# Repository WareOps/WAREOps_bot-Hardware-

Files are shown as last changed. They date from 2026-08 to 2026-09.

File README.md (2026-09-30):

# Warehouse Bot & Active Vision System (ROS2 Humble)

An end-to-end Autonomous Mobile Robot (AMR) system for warehouse navigation, mapping, and active vision rack inventory scanning developed using **ROS2 Humble**.

---

##  Video Demonstrations & Project Demos



*  **[Watch Complete Project Demonstration Playlist on YouTube](https://youtube.com/playlist?list=PLdkPHi9wHG-M&si=vZzbjLmxS52RyPB2)** — Includes full autonomous navigation tours, SLAM mapping, active vision pan-tilt QR scanning, and hardware testing demonstrations.

---

##  System Architecture & Package Deployment Split

The repository is structured for a multi-device deployment between the **onboard Raspberry Pi 4** (robot hardware control & navigation) and the **Local Computer** (operator station, active vision processing, teleoperation, and visualization).

```text
               +---------------------------------------------------+
               |             Wi-Fi / Network Subnet                |
               +-------------------------+-------------------------+
                                         |
            +----------------------------+----------------------------+
            |                                                         |
            v                                                         v
+-----------------------+                                 +-----------------------+
|   RASPBERRY PI 4    |                                 |   LOCAL COMPUTER    |
| (Robot Controller)    |                                 | (Operator Station)    |
+-----------------------+                                 +-----------------------+
| • pi_bot              |                                 | • active_vision_scanner|
| • serial              |                                 | • joy_teleop          |
| • diffdrive_arduino   |                                 | • rviz                |
+-----------+-----------+                                 | • Motors              |
            |                                             +-----------------------+
            v                                                         |
+-----------------------+                                             |
|  Hardware           |                                             v
| • Arduino Nano        |<============================================+
| • RPLidar A1M8        |   (ESP32-CAM MJPEG Stream & WiFi Servo HTTP)
| • Motor Drivers       |
+-----------------------+
```

---

##  Package Distribution Guide

###  Packages to clone on **Raspberry Pi** (Robot Hardware & Navigation)

| Package | Description |
|---|---|
| **`pi_bot`** | Core robot ROS2 bringup, URDF/Xacro models, RPLidar launch, SLAM Toolbox configurations, and Navigation2 launch stack. |
| **`serial`** | C++ serial library required by `diffdrive_arduino` to communicate over USB with the Arduino motor controller. |
| **`diffdrive_arduino`** | `ros2_control` hardware interface C++ plugin interfacing with Arduino Nano for differential drive wheel odometry and motor commands. |

###  Packages to clone on **Local Computer** (Workstation & Vision Processing)

| Package | Description |
|---|---|
| **`active_vision_scanner`** | Python ROS2 node for OpenCV active rack alignment, pan-tilt servo tracking, QR code scanner, database lookup (`warehouse_database.xlsx`), and CSV inventory logging. |
| **`joy_teleop`** | ROS2 node mapping USB joystick / gamepad input to `/cmd_vel` velocity commands for manual robot control. |
| **`rviz`** | Pre-configured RViz2 display profiles (`rviz_config.rviz`, `rviz_config_nav2.rviz`) for live map, costmap, TF, and LiDAR visualization. |
| **`Motors`** | Arduino Nano firmware (`ROSArduinoBridge`) sketch and driver headers for motor control, PID tuning, and encoder processing. |

---

##  Quick Start Guide

### 1. Prerequisites & Dependencies

Both machines must run **Ubuntu 22.04 LTS** with **ROS2 Humble** installed.

On **Raspberry Pi**:
```bash
sudo apt update
sudo apt install -y \
  ros-humble-ros2-control \
  ros-humble-ros2-controllers \
  ros-humble-slam-toolbox \
  ros-humble-navigation2 \
  ros-humble-nav2-bringup \
  ros-humble-rplidar-ros
```

On **Local Computer**:
```bash
sudo apt update
sudo apt install -y \
  ros-humble-rviz2 \
  ros-humble-joy \
  python3-opencv \
  python3-pandas \
  python3-openpyxl
pip install pyzbar "numpy<2"
```

---

### 2. Setting Up on Raspberry Pi

1. Create a ROS2 workspace and clone the Pi packages:
   ```bash
   mkdir -p ~/ros2_ws/src
   cd ~/ros2_ws/src
   # Copy or git clone pi_bot, serial, diffdrive_arduino into src/
   ```

2. Build and source:
   ```bash
   cd ~/ros2_ws
   colcon build --symlink-install
   source install/setup.bash
   ```

3. Export ROS Domain ID (must match Local PC):
   ```bash
   echo "export ROS_DOMAIN_ID=0" >> ~/.bashrc
   source ~/.bashrc
   ```

---

### 3. Setting Up on Local Computer

1. Create a ROS2 workspace and clone the Local PC packages:
   ```bash
   mkdir -p ~/ros2_ws/src
   cd ~/ros2_ws/src
   # Copy or git clone active_vision_scanner, joy_teleop, rviz, Motors into src/
   ```

2. Build and source:
   ```bash
   cd ~/ros2_ws
   colcon build --symlink-install
   source install/setup.bash
   ```

3. Export ROS Domain ID (must match Raspberry Pi):
   ```bash
   echo "export ROS_DOMAIN_ID=0" >> ~/.bashrc
   source ~/.bashrc
   ```

---

##  Running the System

### On Raspberry Pi (Robot Hardware Bringup):

```bash
# 1. Bring up robot state publisher and diffdrive hardware interface
ros2 launch pi_bot launch_robot.launch.py 

# 2. Launch SLAM Toolbox for mapping (or navigation for autonomous drive)
ros2 launch pi_bot slam_map.launch.py

# 3. Launch Nav2_bringup (navigation for autonomous drive with delayed initial pose setup)
ros2 launch pi_bot navigation.launch.py map:=/path/to/my_map.yaml

# 4. Optional: Run autonomous rack navigation script or full tour manager
python3 scripts/go_to_rack_r4_a3.py
python3 scripts/full_tour.py
```

### On Local Computer (Control & Inspection):

```bash
# 1. Run Joystick Teleop for manual navigation
ros2 launch joy_teleop teleop.launch.py

# 2. Launch RViz2 for visualization
rviz2 -d src/rviz/rviz_config_nav2.rviz

# 3. Launch Active Vision Scanner System
ros2 launch active_vision_scanner scanner_system.launch.py \
    esp32_ip:=192.168.43.XXX \
    esp32_cam_url:=http://192.168.43.YYY:81/stream
```

---

##  Repository Directory Tree

```text
src/
├── active_vision_scanner/  # [Local PC] ESP32 WiFi bridge & OpenCV QR scanner state machine
├── Chassis_step_file/      # 3D CAD step model file of the WareOps robot chassis
├── diffdrive_arduino/      # [Raspberry Pi] ros2_control C++ hardware interface plugin
├── Images/                 # High-resolution hardware and assembly gallery with README.md
├── joy_teleop/             # [Local PC] Joystick teleoperation node
├── Motors/                 # [Local PC] Arduino Nano motor firmware (ROSArduinoBridge)
├── pi_bot/                 # [Raspberry Pi] URDF, RPLidar driver, SLAM, & Nav2 launch configs
├── rviz/                   # [Local PC] RViz2 display configuration files
├── scripts/                # Autonomous navigation waypoint & full tour sequence scripts
│   ├── initialise.py       # Delayed initial pose setup script for Nav2
│   ├── full_tour.py        # Multi-rack automated inspection sequence manager
│   ├── go_to_rack_r3_b3.py # Waypoint navigation script for Rack R3_B3
│   ├── go_to_rack_r4_a2.py # Waypoint navigation script for Rack R4_A2
│   └── go_to_rack_r4_a3.py # Waypoint navigation script for Rack R4_A3
├── serial/                 # [Raspberry Pi] Serial communication C++ library
├── HARDWARE.md             # Complete hardware specification sheet
├── system_overview.md       # Detailed active vision system flow documentation
├── warehouse_database.xlsx # Master warehouse inventory Excel database
└── warehouse_database.ods  # Excel/ODS master inventory database file
```

---

##  Documentation Links
* [HARDWARE.md](HARDWARE.md): Detailed hardware connections, pinouts, and power distribution specs.
* [system_overview.md](system_overview.md): Complete breakdown of network architecture, ESP32 pan-tilt trajectory, and vision state machine flow.

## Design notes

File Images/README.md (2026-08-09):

# WareOps Bot - Hardware & Assembly Gallery

This directory contains high-resolution photographs detailing the physical hardware, internal electronics, sensor integration, wiring layout, and 3D-printing manufacturing process of the **WareOps Autonomous Warehouse Inspection Robot**.

---

## 🤖 System Overview & Feature Architecture

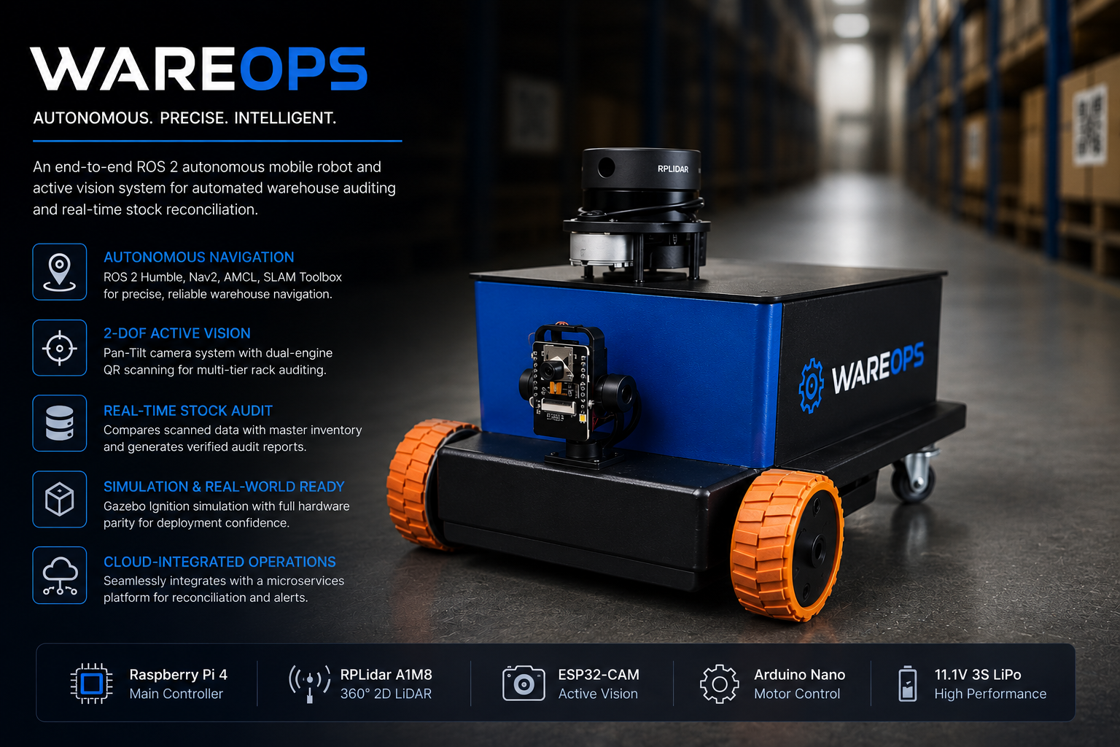
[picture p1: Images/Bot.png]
WareOps Bot System Overview

*WareOps Autonomous Mobile Robot hardware architecture, active vision pan-tilt system, sensor suite, and system capabilities overview.*

---

## 📸 Assembled Robot Views

### Robot Perspective Overview
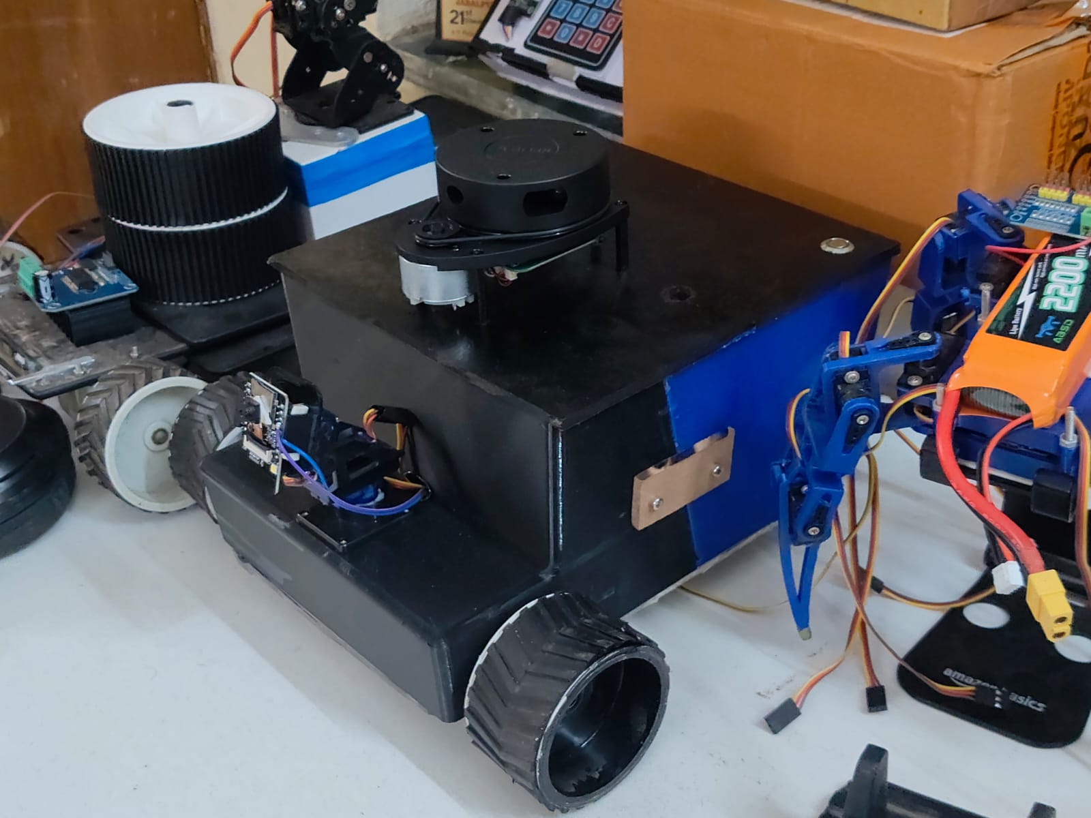
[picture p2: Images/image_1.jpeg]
WareOps Bot Side Perspective

*Side perspective view of the fully assembled robot showing the top-mounted RPLiDAR A1, front pan/tilt camera scanner, and differential drive wheels.*

### Front View & Sensor Alignment
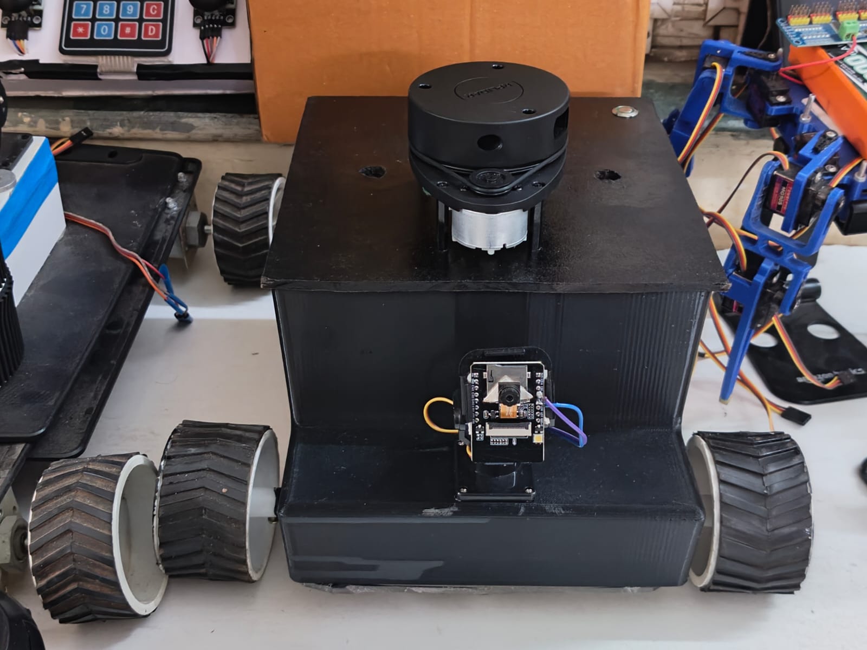
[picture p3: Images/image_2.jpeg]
WareOps Bot Front View

*Front view highlighting the active vision camera module mounted on a pan/tilt servo assembly and the top LiDAR.*

### Front-Isometric View
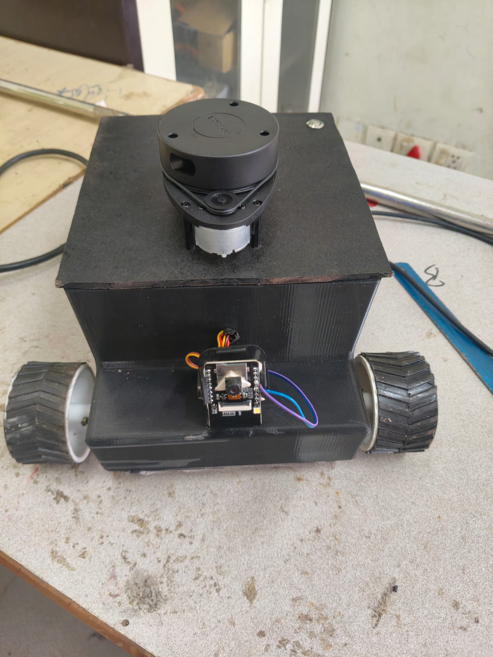
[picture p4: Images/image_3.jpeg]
WareOps Bot Isometric View

*Isometric view showing compact chassis design and wheel mounting.*

### Front Sensor Array
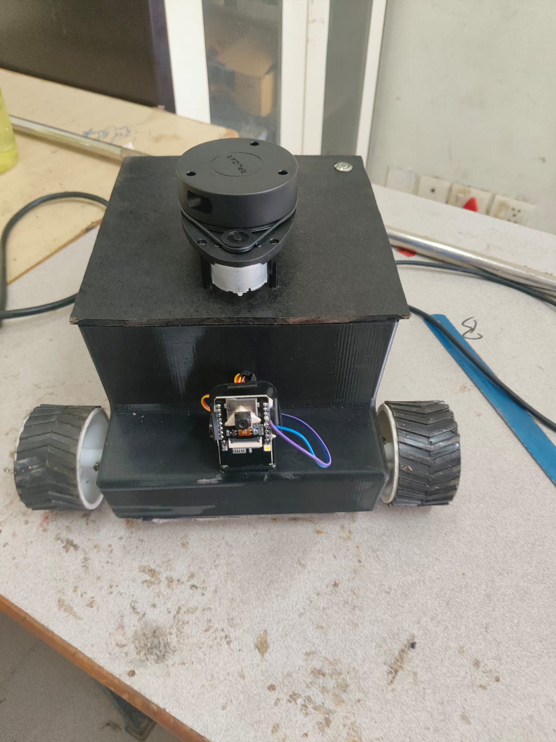
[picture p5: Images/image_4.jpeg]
WareOps Bot Sensor Array

*Close-up front view detailing sensor positioning for autonomous navigation and barcode/QR rack scanning.*

### Floor Navigation Testing
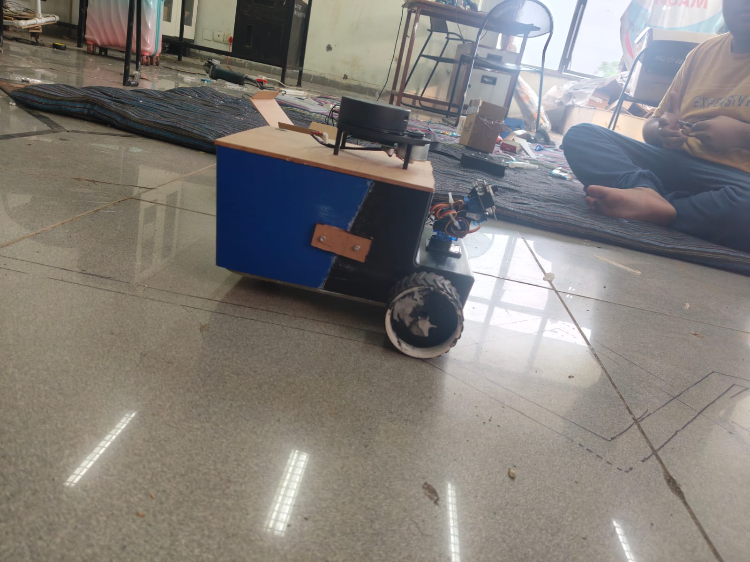
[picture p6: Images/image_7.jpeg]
WareOps Bot Floor Test

*Side profile of assembled robot undergoing mobility and ground-truth transform testing.*

### Navigation Test Grid
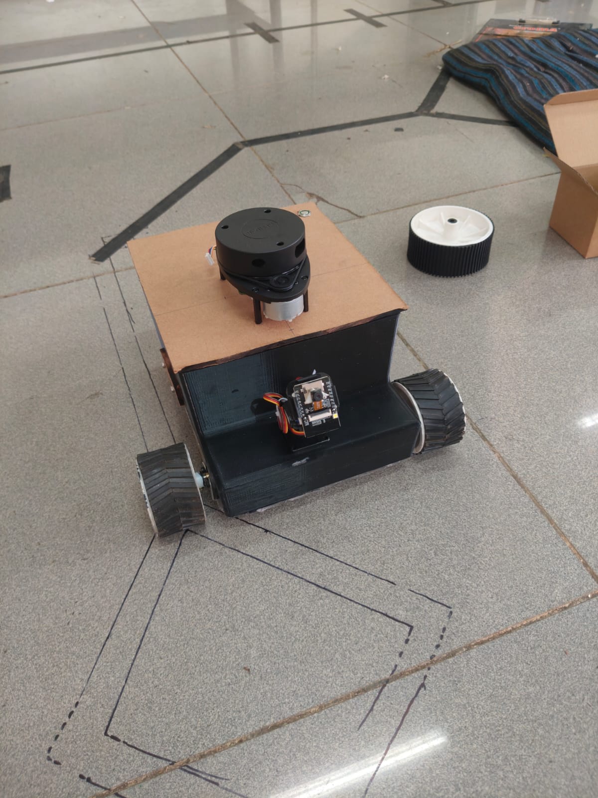
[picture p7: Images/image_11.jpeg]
WareOps Bot Navigation Grid

*Robot positioned on floor layout grid during AMCL localization calibration.*

---

## ⚡ Internal Electronics & Control Hardware

### Electronics Bay Overview
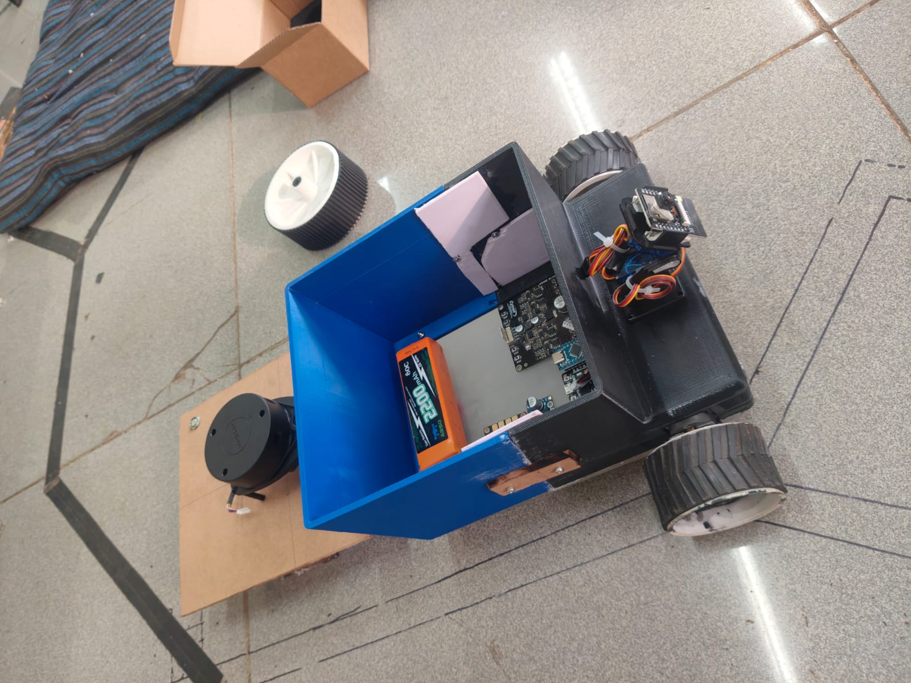
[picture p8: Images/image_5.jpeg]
Internal Electronics Layout

*Open chassis compartment displaying the LiPo battery placement, Cytron motor driver, and main controller board.*

### Control Board & Power Layout
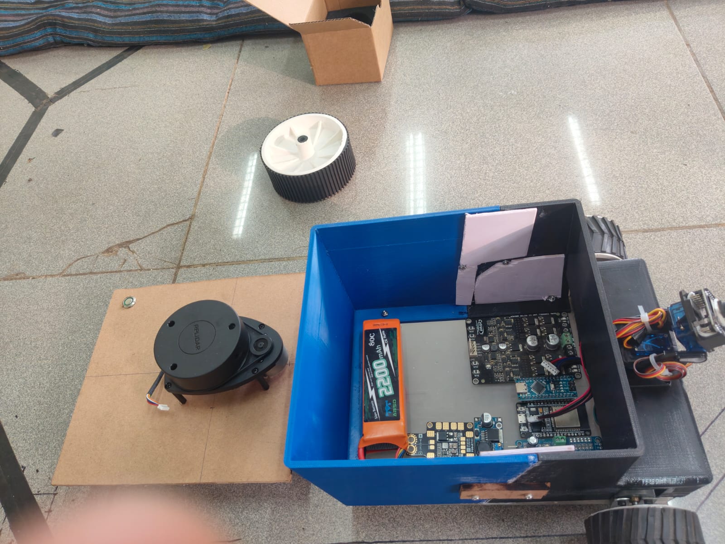
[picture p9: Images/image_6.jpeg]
Top Down Component View

*Top-down layout showing Cytron motor driver, microcontroller control board, DC-DC buck converters, and 2200mAh 3S LiPo battery.*

### Component Placement & Power Distribution
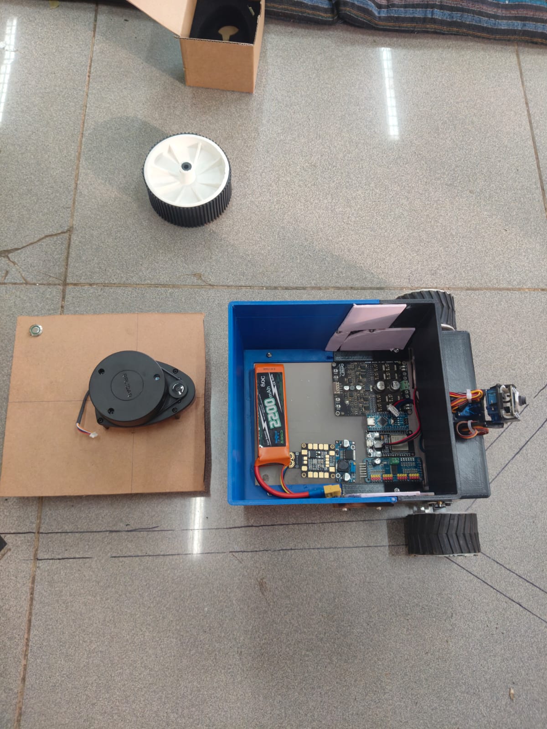
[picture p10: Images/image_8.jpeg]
Component Layout

*Overhead component mapping with top mounting plate detached.*

### High-Angle Hardware Layout
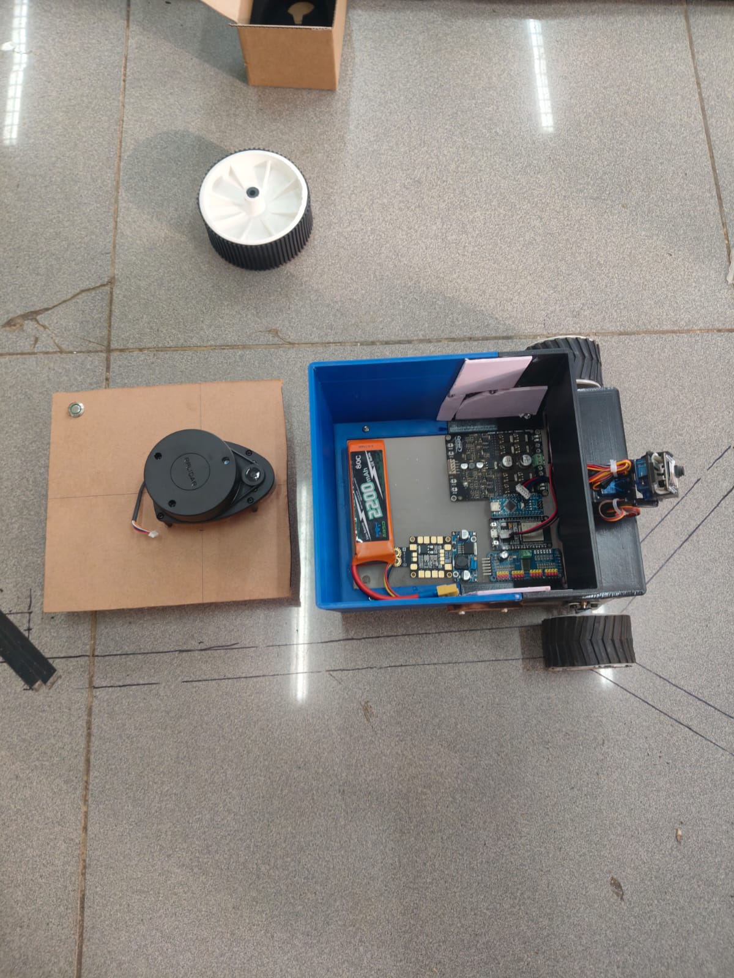
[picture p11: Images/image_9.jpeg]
High Angle Assembly Layout

*Component layout reference prior to top plate installation.*

### Electronics Board Close-Up
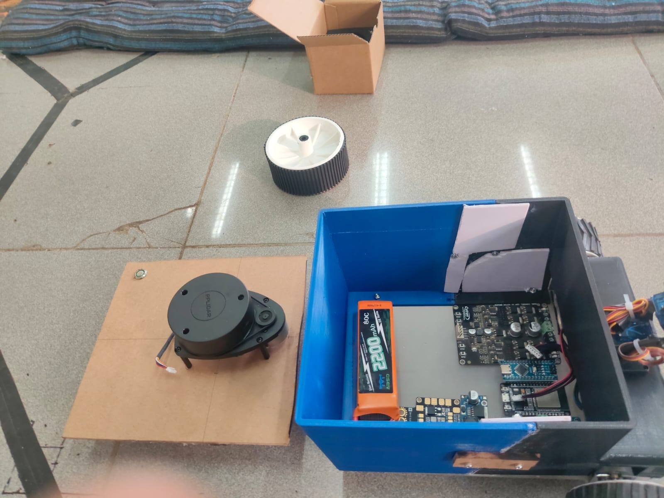
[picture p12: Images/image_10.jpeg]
Electronics Boards Close-Up

*Detailed close-up of motor drive electronics, power distribution circuitry, and microcontroller interconnects.*

### Internal Wiring & Harness
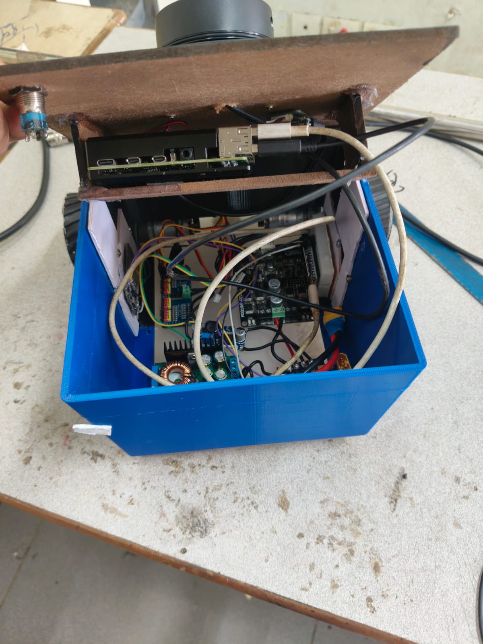
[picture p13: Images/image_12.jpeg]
Internal Wiring Harness

*Detailed view of internal cabling, USB interconnects, DC power wiring, and sensor communication lines.*

---

## 🖨️ 3D Printing & Manufacturing

### Chassis Printing Process
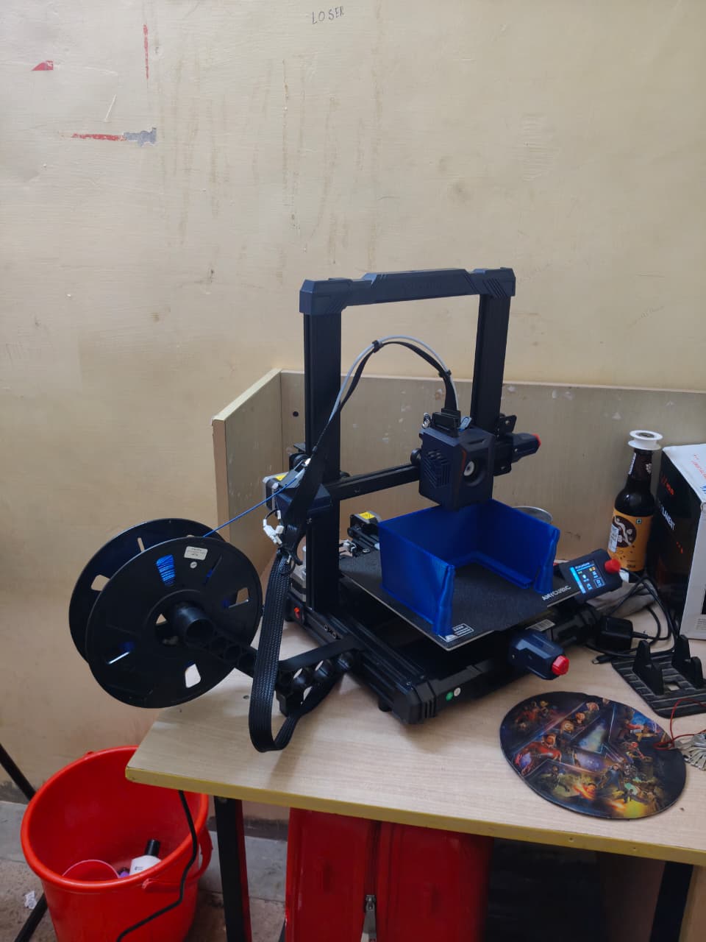
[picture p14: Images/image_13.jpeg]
3D Printing Chassis Body

*Fabrication of the main blue robot chassis enclosure using an Anycubic FDM 3D printer.*

### Print Bed Fabrication Detail
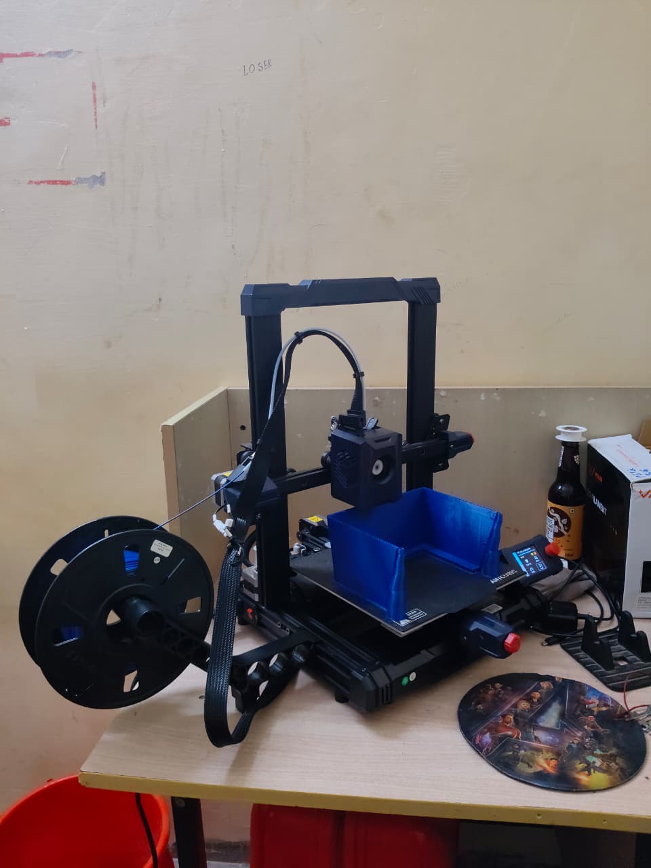
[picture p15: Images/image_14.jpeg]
3D Printer Bed Close-Up

*Close-up view of the custom 3D printed body shell during printing process.*

---

## 🛠️ Hardware Specification Summary

- **Main Controller**: Raspberry Pi 4 (ROS 2 Humble, Nav2, AMCL, SLAM Toolbox)
- **Motor Control**: Arduino Nano & Cytron Dual-Channel DC Motor Driver
- **LiDAR Sensor**: RPLidar A1M8 360° 2D Laser Scanner
- **Active Vision System**: ESP32-CAM Pan/Tilt 2-DOF Camera Module for multi-tier rack QR/barcode auditing
- **Power System**: 11.1V 3S High Performance LiPo Battery with DC-DC Buck Converters
- **Chassis**: Custom 3D-Printed High-Durability Modular Enclosure

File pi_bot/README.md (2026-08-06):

# `pi_bot` — ROS2 Robot Bringup & Navigation Package

**Deployment Target**: 🔴 **Raspberry Pi**

`pi_bot` is the core ROS2 bringup package installed directly on the Raspberry Pi 4 onboard the robot. It contains the robot's URDF description, `ros2_control` configuration, LiDAR integration, SLAM Toolbox mapping parameters, and Navigation2 launch setup.

---

## 📁 Package Structure

```text
pi_bot/
├── config/
│   ├── my_controllers.yaml  # ros2_control diff_drive_controller & joint_state_broadcaster
│   ├── param_nav2.yaml      # Navigation2 stack parameters (AMCL, Planner, Controller)
│   ├── Slam_param.yaml      # SLAM Toolbox online async mapping parameters
│   └── twist_mux.yaml       # Velocity multiplexer priority setup
├── launch/
│   ├── launch_robot.launch.py # Main hardware bringup (robot_state_publisher + controller_manager)
│   ├── navigation.launch.py   # Nav2 navigation stack launch
│   ├── rplidar.launch.py      # RPLidar A1M8 node launch
│   ├── rsp.launch.py          # Robot State Publisher standalone launch
│   └── slam_map.launch.py     # SLAM Toolbox mapping launch
├── urdf/
│   ├── robot_base.urdf.xacro  # Top-level URDF xacro entry point
│   ├── base_mobile.xacro     # Chassis geometry, wheel links, and caster wheels
│   ├── ros2_control.xacro    # Hardware interface integration (diffdrive_arduino)
│   └── common_properties.xacro # Inertia macros and color materials
├── CMakeLists.txt
└── package.xml
```

---

## 🛠️ Dependencies

Ensure the following packages are installed on your Raspberry Pi:
```bash
sudo apt update
sudo apt install -y \
  ros-humble-ros2-control \
  ros-humble-ros2-controllers \
  ros-humble-robot-state-publisher \
  ros-humble-xacro \
  ros-humble-rplidar-ros \
  ros-humble-slam-toolbox \
  ros-humble-navigation2 \
  ros-humble-nav2-bringup
```

You must also have `serial` and `diffdrive_arduino` cloned and built in the same ROS2 workspace on the Raspberry Pi.

---

## 🚀 Usage & Launch Instructions

### 1. Bring Up Robot Hardware & Controllers
Converts xacro to URDF, starts `robot_state_publisher`, initializes `controller_manager`, and loads `diff_cont` and `joint_broad`:
```bash
ros2 launch pi_bot launch_robot.launch.py
```

### 2. Launch RPLidar A1M8
Publishes 2D laser scan data to `/scan` topic over USB serial (`/dev/ttyUSB0` or `/dev/ttyACM0`):
```bash
ros2 launch pi_bot rplidar.launch.py
```

### 3. Launch SLAM Toolbox (Mapping Mode)
Launches 2D mapping mode to generate a map of the environment:
```bash
ros2 launch pi_bot slam_map.launch.py
```

### 4. Launch Navigation2 Stack
Launches path planning, costmaps, and obstacle avoidance using pre-configured parameters. Automatically includes delayed execution (8s) of `/home/abhinav/warehouse_bot_simulation_ws/src/scripts/initialise.py` to set initial pose once Nav2 lifecycle nodes are active:
```bash
ros2 launch pi_bot navigation.launch.py map:=/path/to/my_map.yaml
```

---

## 📡 Published & Subscribed Topics

| Topic | Type | Description |
|---|---|---|
| `/cmd_vel` | `geometry_msgs/msg/Twist` | Input velocity command for wheel motion |
| `/diff_cont/cmd_vel_unstamped` | `geometry_msgs/msg/Twist` | Unstamped velocity command sent to controller |
| `/scan` | `sensor_msgs/msg/LaserScan` | 2D LiDAR range measurements |
| `/tf` / `/tf_static` | `tf2_msgs/msg/TFMessage` | Robot coordinate frame transforms (`base_link` -> `laser_frame`, etc.) |
| `/odom` | `nav_msgs/msg/Odometry` | Wheel odometry computed by `diffdrive_arduino` |

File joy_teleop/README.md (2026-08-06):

# `joy_teleop` — ROS2 Joystick Teleoperation Package

**Deployment Target**: 🔵 **Local Computer**

`joy_teleop` is a ROS2 package running on the operator's Local Computer that converts joystick / gamepad controller inputs (such as USB gamepads, PlayStation, or Xbox controllers) into:
- `geometry_msgs/msg/Twist` velocity commands for robot drive control
- `std_msgs/msg/String` JSON servo commands for camera yaw/pitch control (forwarded to the ESP32 via `esp32_wifi_bridge`)

---

## 📁 Package Structure

```text
joy_teleop/
├── joy_teleop/
│   ├── __init__.py
│   └── teleop_node.py  # Maps joystick axes/buttons → drive velocity + camera servo commands
├── launch/
│   └── teleop.launch.py # Launches joy_node (ros-humble-joy) and ps2_teleop
├── resource/
├── setup.cfg
├── setup.py
└── package.xml
```

---

## 🛠️ Prerequisites & Installation

On your **Local Computer**, install the ROS2 joystick driver package:
```bash
sudo apt update
sudo apt install -y ros-humble-joy
```

Connect your joystick via USB. Verify system recognition:
```bash
ls -l /dev/input/js*
```

---

## 🚀 Usage & Launch Instructions

### 1. Build Package
```bash
cd ~/warehouse_bot_simulation_ws
colcon build --packages-select joy_teleop
source install/setup.bash
```

### 2. Run Nodes (3 terminals)

**Terminal 1 — Joy driver** (reads physical controller):
```bash
source ~/warehouse_bot_simulation_ws/install/setup.bash
ros2 run joy joy_node
```

**Terminal 2 — Teleop node** (this package):
```bash
source ~/warehouse_bot_simulation_ws/install/setup.bash
ros2 run joy_teleop teleop_node
```

**Terminal 3 — ESP32 WiFi Bridge** (forwards servo commands to hardware):
```bash
source ~/warehouse_bot_simulation_ws/install/setup.bash
ros2 run active_vision_scanner esp32_bridge --ros-args -p esp32_ip:=<YOUR_ESP32_IP>
```

> The ESP32 bridge is required for camera servo commands to reach the hardware. The drive commands work independently of it.

---

## 🎮 Controls & Button Mapping

### Drive Control

| Input | Action | Notes |
|---|---|---|
| **Left Stick (Vertical)** | Linear velocity (`+x` forward) | Axis index `1` |
| **Right Stick (Horizontal)** | Angular velocity (`z` rotation) | Axis index `2` |
| **D-Pad Up / Down** | Increase / Decrease linear speed | 10% per press, range: 0.1–5.0 m/s |
| **D-Pad Right / Left** | Decrease / Increase angular speed | 10% per press, range: 0.2–5.0 rad/s |

### Camera Servo Control (Right-Side Face Buttons)

Each button press moves the servo by **5°**. Limits are hardware-enforced.

| Button | Index | Action | Servo Axis | Limit |
|---|---|---|---|---|
| **Y** | `4` | Pitch **UP** (tilt camera up) | Pitch − 5° | Min **20°** |
| **A** | `0` | Pitch **DOWN** (tilt camera down) | Pitch + 5° | Max **160°** |
| **B** | `1` | Yaw **RIGHT** | Yaw + 5° | Max **180°** |
| **X** | `3` | Yaw **LEFT** | Yaw − 5° | Min **0°** |

### Camera Preset Positions

| Button | Index | Action | Yaw | Pitch |
|---|---|---|---|---|
| **SELECT** | `10` | → **Parked** position (stowed) | 100° | 90° |
| **START** | `11` | → **Default Scan** position (faces rack) | 10° | 90° |

> Preset positions match the `PARKED_YAW/PITCH` and `DEFAULT_YAW/PITCH` constants defined in `active_vision_scanner/rack_scanner_node.py`.

---

## 📡 Published & Subscribed Topics

| Topic | Type | Direction | Description |
|---|---|---|---|
| `/joy` | `sensor_msgs/msg/Joy` | **Subscribed** | Raw controller axes and button states |
| `/diff_cont/cmd_vel_unstamped` | `geometry_msgs/msg/Twist` | **Published** | Robot drive velocity commands |
| `/camera_servo_cmd` | `std_msgs/msg/String` | **Published** | JSON servo commands → `esp32_wifi_bridge` |

### Servo Command JSON Format

```json
{"cmd": "MOVE", "pitch": 90, "yaw": 100, "speed": 20}
```

---

## 🔧 Adjusting Button Indices

Controller button indices vary by manufacturer. To find your controller's indices, run:

```bash
ros2 topic echo /joy
```

Press each button and observe which index in the `buttons: [...]` array changes from `0` to `1`. Then update the corresponding variables in `teleop_node.py`:

```python
self.btn_A      = 0    # Pitch DOWN
self.btn_B      = 1    # Yaw RIGHT
self.btn_X      = 3    # Yaw LEFT
self.btn_Y      = 4    # Pitch UP
self.btn_SELECT = 10   # Go to PARKED position
self.btn_START  = 11   # Go to DEFAULT SCAN position
```

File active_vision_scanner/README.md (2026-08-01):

# `active_vision_scanner` — Active Vision Rack Scanning System

**Deployment Target**: 🔵 **Local Computer**

## Network Architecture

All devices connect to the **same mobile hotspot**:

```
+-----------------------------------------------------------------------+
|                         📱 MOBILE HOTSPOT                             |
|                        (WiFi: 192.168.43.x)                           |
+-----------------------------------+-----------------------------------+
                                    |
          +-------------------------+-------------------------+
          |                                                   |
          v                                                   v
+-------------------+                               +-------------------+
|    📷 ESP32-CAM   |                               | 🎮 ESP32 DEV KIT  |
| Video Stream      |                               | HTTP Server (:80) |
| :81/stream        |                               | PCA9685 Servos    |
+---------^---------+                               +---------^---------+
          |                                                   |
          | HTTP GET (MJPEG)                                  | HTTP POST (/cmd)
          |                                                   |
+---------+---------------------------------------------------+---------+
|                                💻 LAPTOP                              |
|                                                                       |
|   [rack_scanner_node.py]                       [esp32_wifi_bridge.py] |
|   (OpenCV + State Machine)                      (ROS2 <-> HTTP Bridge)|
+-----------------------------------------------------------------------+
```

---

## Files & Data Architecture

### Core Files

| File | Purpose |
|---|---|
| [scanner_system.launch.py](launch/scanner_system.launch.py) | ROS2 Launch file — launches both bridge & scanner with custom parameters |
| [rack_scanner_node.py](active_vision_scanner/rack_scanner_node.py) | ROS2 OpenCV node — state machine, edge/pitch adjustment, QR detection, database lookup, and CSV logging |
| [esp32_serial_bridge.py](active_vision_scanner/esp32_serial_bridge.py) | ROS2 → ESP32 WiFi HTTP bridge |
| [esp32_servo_controller.ino](esp32_servo_controller/esp32_servo_controller.ino) | ESP32 Arduino firmware — WiFi HTTP server + PCA9685 |
| [package.xml](package.xml) | ROS2 package manifest |
| [setup.py](setup.py) | Python package setup |

### Database & Outputs (Workspace `src/`)

| File / Path | Type | Purpose |
|---|---|---|
| [warehouse_database.xlsx](../warehouse_database.xlsx) | Excel (xlsx) Input | Master database containing QR codes, product codes, serial numbers, and expected shelf positions (`Aisle`, `Row`, `Rack`, `Shelf`). |
| [scanned_inventory.csv](../scanned_inventory.csv) | CSV Output | Appends all successfully verified, correctly placed product scans with timestamps. |
| `scanned_Aisle_<A>_Row_<R>_Rack_<RK>.csv` | CSV Output | A location-specific CSV compiled after each scan cycle containing only correctly placed items at that location. |
| [mismatch_log.csv](../mismatch_log.csv) | CSV Output | Logs all misplaced products (incorrect shelf/rack/aisle) and completely unknown QR codes with detailed mismatch warning messages. |

---

## Physical Parameters

| Parameter | Value |
|---|---|
| Camera height from ground | **13.35 cm** |
| Rack height | **49 cm** |
| Rack horizontal width | **60 cm** |
| Camera distance from rack | **40 cm** |
| Number of shelves | **4** |
| Parked position | **Yaw = 100°, Pitch = 90°** |
| Scanning / Detection position | **Yaw = 10°, Pitch = 90°** |
| Pitch tilt range | **20° (Min Tilt UP) to 160° (Max Tilt DOWN)** |

---

## ROS2 Topics

| Topic | Type | Publisher | Subscriber | Purpose |
|---|---|---|---|---|
| `/bot_status` | `String` | Robot nav / Scanner | Scanner / Robot nav | `"Reached Aisle_1/Row_1/Rack_1"` triggers scan; `"Succeeded Aisle_1/Row_1/Rack_1"` = done |
| `/camera_servo_cmd` | `String` | Scanner | WiFi Bridge | JSON servo commands forwarded via HTTP POST |
| `/camera_system` | `String` | External | Scanner + Bridge | `"stop"` → shutdown everything |
| `/esp32_response` | `String` | WiFi Bridge | (debug) | ESP32 HTTP responses |

---

## State Machine Flow

```
 [START] ---> (IDLE) ─────────► Receive "Reached Aisle_X/Row_Y/Rack_Z" on /bot_status
                 │
                 ▼
          (MOVING_TO_SCAN) ───► Move servos to Yaw=0°, Pitch=90°
                 │
                 ▼
         (ADJUSTING_PITCH) ───► OpenCV Canny edge pitch alignment (~74.4°)
                 │
                 ▼
            (SCANNING) ───────► Phase 1: Centered Scan (10 frames)
                 │              Phase 2: Active Pitch Tilt Sweep (S1-S4)
                 │              Database Validation & CSV Export
                 ▼
          (MOVING_TO_PARK) ───► Move servos to Yaw=90°, Pitch=90°
                 │
                 ▼
               (IDLE) ────────► Publish "Succeeded..." on /bot_status
```

**Sequence per rack:**
1. Receive `"Reached Aisle_1/Row_1/Rack_1"` on `/bot_status`.
2. Parse location into Aisle `A1`, Row `R1`, Rack `RK1`.
3. Command servos to default scan orientation (yaw 90° → 0°, pitch stays 90°).
4. Auto-adjust pitch until all 4 shelves are visible (~74.4°).
5. Capture frames in 2 phases (Centered View + Active Pitch Tilt Sweep for top/bottom shelves).
6. Query each detected QR against `warehouse_database.xlsx` using `openpyxl`.
   - **Correct Placement**: Logged to `scanned_inventory.csv` and compiled into `scanned_Aisle_1_Row_1_Rack_1.csv`.
   - **Incorrect Placement / Unknown**: Logged to `mismatch_log.csv` with a descriptive message.
7. Publish `"Succeeded Reached Aisle_1/Row_1/Rack_1"` on `/bot_status`.
8. Return servos back to yaw 90°, pitch 90° (parked).

---

## CSV Logging Format

### 1. Correct Inventory Log (`scanned_inventory.csv`)
```csv
Timestamp,Scanned_Location,Aisle,Row,Rack,Shelf,QR_Code,Product_Code,Product_Serial_Number,Category_Number
2026-07-25 16:11:52,Aisle_1/Row_1/Rack_1,A1,R1,RK1,S1,%U0fd,WH-A1-R1-RK1-S1-P1,SN-00001,CAT-01
```

### 2. Mismatch Log (`mismatch_log.csv`)
```csv
Timestamp,Current_Location,Current_Aisle,Current_Row,Current_Rack,Current_Shelf,QR_Code,Product_Code,Product_Serial_Number,Category_Number,Expected_Aisle,Expected_Row,Expected_Rack,Expected_Shelf,Message
2026-07-25 16:11:52,Aisle_1/Row_1/Rack_1,A1,R1,RK1,S1,i#S20,WH-A1-R1-RK1-S2-P1,SN-00004,CAT-02,A1,R1,RK1,S2,At position Aisle_1/Row_1/Rack_1/S1 this QR product (WH-A1-R1-RK1-S2-P1) is there but it should be in position Aisle_1/Row_1/Rack_1/S2
```

---

## ESP32 Servo Trajectory Planning

The ESP32 **never jumps** to a target angle. Both servos move simultaneously:

```
Yaw:   90° → 89° → 88° → ... → 1° → 0°    (+1/-1° per step)
Pitch: 90° → 90° (no change needed)          (stays put)

Each step: 15ms delay (configurable via "speed" in JSON)
```

---

## How to Run

### 1. Launch Everything via Single Launch File (Recommended)

```bash
# Build and source workspace
cd ~/warehouse_bot_simulation_ws
colcon build --packages-select active_vision_scanner
source install/setup.bash

# Launch both bridge and scanner with your target IP address & stream URL:
ros2 launch active_vision_scanner scanner_system.launch.py \
    esp32_ip:=192.168.43.XXX \
    esp32_cam_url:=http://192.168.43.YYY:81/stream
```

### 2. Manual Terminal Launch (Alternative)

```bash
# Terminal 1: Run the WiFi bridge
ros2 run active_vision_scanner esp32_bridge \
    --ros-args -p esp32_ip:=192.168.43.XXX

# Terminal 2: Run the scanner node
ros2 run active_vision_scanner rack_scanner \
    --ros-args -p esp32_cam_url:=http://192.168.43.YYY:81/stream

# Terminal 3: Test — simulate bot reaching a rack
ros2 topic pub --once /bot_status std_msgs/msg/String \
    "data: 'Reached Aisle_1/Row_1/Rack_1'"
```

> [!NOTE]
> Python environment NumPy mismatch has been resolved by pinning `numpy<2` (installed 1.26.4). This ensures full compatibility with OpenCV and Pandas.

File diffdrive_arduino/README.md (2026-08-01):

# `diffdrive_arduino` — ROS2 Control Hardware Interface for Arduino

**Deployment Target**: 🔴 **Raspberry Pi**

`diffdrive_arduino` is a C++ `ros2_control` hardware interface plugin designed to bridge ROS2 controllers (`diff_drive_controller`, `joint_state_broadcaster`) with an Arduino Nano running the `ROSArduinoBridge` motor controller firmware.

---

## ⚙️ How It Works

```text
[ROS2 Twist Command]
        │
        ▼
[diff_drive_controller]
        │
        ▼
[diffdrive_arduino (Hardware Interface Plugin)]
        │ (Uses serial library over /dev/ttyACM0 @ 57600 baud)
        ▼
[Arduino Nano (ROSArduinoBridge Firmware)]
        │
        ▼
[Cytron MDD10A Driver + TTN25 Encoder Motors]
```

1. **Read Loop**: Sends `e\r` over serial to query left and right wheel encoder counts from Arduino Nano. Calculates wheel position (rad) and velocity (rad/s) and updates ROS state.
2. **Write Loop**: Converts target wheel angular velocities into motor PWM counts and sends `m <left_speed> <right_speed>\r` to Arduino Nano.

---

## 📁 Package Structure

```text
diffdrive_arduino/
├── include/diffdrive_arduino/
│   ├── arduino_comms.hpp     # Serial communication wrapper
│   ├── diffdrive_robot.hpp     # SystemInterface hardware implementation
│   ├── fake_robot.hpp          # Simulated hardware interface for testing
│   └── wheel.hpp               # Wheel state data structure
├── src/
│   ├── arduino_comms.cpp
│   ├── diffdrive_robot.cpp
│   ├── fake_robot.cpp
│   └── wheel.cpp
├── launch/
│   ├── fake_robot.launch.py    # Launch script using fake hardware
│   └── test_robot.launch.py    # Launch script using physical Arduino hardware
├── robot_hardware.xml          # Pluginlib export manifest for physical robot
├── fake_robot_hardware.xml     # Pluginlib export manifest for fake robot
├── CMakeLists.txt
└── package.xml
```

---

## 🛠️ Requirements & Dependencies

- **Hardware**: Raspberry Pi 4, Arduino Nano (flashed with `ROSArduinoBridge` firmware), USB-A to USB-B Mini cable.
- **Dependencies**:
  - `ros2_control`
  - `hardware_interface`
  - `pluginlib`
  - `serial` (cloned in workspace)

---

## 🚀 Usage Instructions

### 1. Build Package
```bash
cd ~/ros2_ws
colcon build --packages-select diffdrive_arduino
source install/setup.bash
```

### 2. Standalone Testing (Physical Hardware)
To test serial connection to Arduino on `/dev/ttyACM0` at `57600` baud:
```bash
ros2 launch diffdrive_arduino test_robot.launch.py
```

### 3. Standalone Testing (Simulated Hardware)
To verify ros2_control controller loading without physical hardware attached:
```bash
ros2 launch diffdrive_arduino fake_robot.launch.py
```

---

## ⚙️ Integration with URDF (`ros2_control.xacro`)

This package is registered via `pluginlib` and configured inside `pi_bot/urdf/ros2_control.xacro`:

```xml
<ros2_control name="RealRobot" type="system">
    <hardware>
        <plugin>diffdrive_arduino/DiffDriveArduino</plugin>
        <param name="left_wheel_name">left_wheel_joint</param>
        <param name="right_wheel_name">right_wheel_joint</param>
        <param name="loop_rate">30</param>
        <param name="device">/dev/ttyACM0</param>
        <param name="baud_rate">57600</param>
        <param name="timeout">1000</param>
        <param name="enc_counts_per_rev">1920</param>
    </hardware>
    ...
</ros2_control>
```

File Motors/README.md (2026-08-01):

# `Motors` — Arduino Motor Firmware Package (`ROSArduinoBridge`)

**Deployment Target**: 🔵 **Local Computer** (Flashed to **Arduino Nano** via USB)

The `Motors` directory contains the Arduino C++ firmware sketch (`ROSArduinoBridge`) designed to run on the **Arduino Nano** microcontroller driving the physical robot's wheels.

Here I have used Mdd10A dual channel motor driver

---

## 📁 Package Structure

```text
Motors/
└── my_bridge/
    └── ROSArduinoBridge/
        ├── ROSArduinoBridge.ino  # Main Arduino sketch entry point & serial command parser
        ├── commands.h            # Serial command byte definitions ('e', 'm', 'r', 'p', 'o')
        ├── diff_controller.h     # Closed-loop PID controller calculation loop
        ├── encoder_driver.h      # Quadrature encoder pin definitions & macros
        ├── encoder_driver.ino    # Encoder interrupt handlers (Pin Change Interrupts)
        ├── motor_driver.h        # Cytron MDD10A motor driver pin mappings
        ├── motor_driver.ino      # PWM & DIR output logic
        ├── sensors.h             # Analog/digital sensor reading headers
        ├── servos.h              # Servo motor control header
        ├── servos.ino            # Servo PWM generation logic
        └── README.md             # Pinout and wiring documentation
```

---

## 🔌 Hardware & Wiring Specifications

### 1. Cytron MDD10A Dual Channel Motor Driver Wiring

| Signal | Arduino Nano Pin | MDD10A Pin | Function |
|---|---|---|---|
| **Left DIR** | `D7` | `M1DIR` | Left motor direction |
| **Left PWM** | `D10` | `M1PWM` | Left motor PWM speed |
| **Right DIR** | `D8` | `M2DIR` | Right motor direction |
| **Right PWM** | `D9` | `M2PWM` | Right motor PWM speed |
| **Enable (EN)** | TBD / +5V | `EN` | Driver enable (connect to +5V) |

### 2. TTN25 Quadrature Encoders Pin Mapping

| Motor | Channel A Pin | Channel B Pin |
|---|---|---|
| **Left Encoder** | `D2` | `D3` |
| **Right Encoder** | `A4` | `A5` |

---

## 💻 Serial Protocol Reference

Baud Rate: **57600 baud** (Carriage Return `\r` required).

| Command | Syntax | Description | Example |
|---|---|---|---|
| **Read Encoders** | `e` | Returns current encoder tick counts for both wheels | `e` -> `1420 1395` |
| **Reset Encoders** | `r` | Resets encoder counters to zero | `r` -> `OK` |
| **Open-Loop Speed** | `o <PWM1> <PWM2>` | Direct PWM drive (-255 to 255) | `o 100 -100` |
| **Closed-Loop Speed** | `m <Spd1> <Spd2>` | Closed-loop PID speed in encoder ticks per loop | `m 15 -15` |
| **Set PID Gains** | `p <Kp> <Kd> <Ki> <Ko>` | Updates PID loop parameters | `p 10 12 0 50` |

> ⚠️ **Safety Timeout**: If no speed commands (`m` or `o`) are received within **2.0 seconds**, the controller automatically stops both motors to prevent runaway conditions.

---

## ⚡ How to Flash Firmware

1. Install the **Arduino IDE** (or Arduino CLI) on your computer.
2. Open `Motors/my_bridge/ROSArduinoBridge/ROSArduinoBridge.ino`.
3. Select Board: **Arduino Nano** (Processor: ATmega328P or ATmega328P Old Bootloader).
4. Connect Arduino Nano via USB. Select the serial port (e.g. `/dev/ttyUSB0` or `/dev/ttyACM0`).
5. Click **Upload**.
6. Verify operation by opening the Serial Monitor at **57600 baud**, sending `e`, and checking for encoder tick responses.

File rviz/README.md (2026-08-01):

# `rviz` — RViz2 Display Profiles & Visualization Package

**Deployment Target**: 🔵 **Local Computer**

The `rviz` directory contains pre-configured RViz2 display profile files (`.rviz`) designed for visualizing the Warehouse Bot on the operator's **Local Computer**.

---

## 📁 Files Included

```text
rviz/
├── rviz_config.rviz       # General visualization profile (Robot model, TF, LiDAR scan, Odometry)
└── rviz_config_nav2.rviz  # Navigation visualization profile (Global/Local Costmaps, Path Plan, AMCL pose)
```

---

## 🛠️ Configuration Details

### 1. `rviz_config.rviz` (General / Teleop Display)
Configured displays:
- **RobotModel**: Renders 3D URDF visualization using `/robot_description` topic.
- **TF Tree**: Visualizes coordinate frames (`map` -> `odom` -> `base_link` -> `laser_frame`).
- **LaserScan**: Renders 2D LiDAR range points from `/scan` topic in red.
- **Odometry**: Plots real-time wheel odometry path from `/odom`.

### 2. `rviz_config_nav2.rviz` (Autonomous Navigation Display)
Configured displays:
- **Global Costmap**: Visualizes global obstacle inflation layer on map frame.
- **Local Costmap**: Visualizes real-time local rolling costmap for dynamic obstacle avoidance.
- **Planner Path**: Renders calculated path trajectory (`/plan` / `/transformed_global_plan`).
- **Particle Cloud**: Displays AMCL particle array for localization estimation uncertainty.
- **2D Pose Estimate**: Interactive tool for setting initial robot pose in AMCL.
- **2D Nav Goal**: Interactive tool for dispatching navigation goals to Navigation2.

---

## 🚀 Usage Instructions

Ensure RViz2 is installed on your **Local Computer**:
```bash
sudo apt update
sudo apt install -y ros-humble-rviz2
```

Launch RViz with your target profile:

### Launch General Visualizer:
```bash
rviz2 -d src/rviz/rviz_config.rviz
```

### Launch Navigation Visualizer:
```bash
rviz2 -d src/rviz/rviz_config_nav2.rviz
```

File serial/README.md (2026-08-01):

# `serial` — Cross-Platform C++ Serial Library

**Deployment Target**: 🔴 **Raspberry Pi**

The `serial` package is a cross-platform C++ library for interfacing with RS-232 serial ports. In this project workspace, it serves as a critical dependency for the `diffdrive_arduino` ROS2 hardware interface package running on the **Raspberry Pi 4**.

---

## 🛠️ Role in Warehouse Bot System

`serial` enables `diffdrive_arduino` to establish raw serial communication over USB (e.g., `/dev/ttyACM0` or `/dev/ttyUSB0`) with the Arduino Nano motor controller:
* Transmitting formatted velocity motor commands (`m <left_speed> <right_speed>\r`).
* Requesting and receiving encoder tick counts (`e\r`).
* Configuring baudrates (default: 57600 baud) and timeout handling.

---

## 📦 Build & Installation

This package is automatically compiled as part of the ROS2 workspace build process on the Raspberry Pi:

```bash
cd ~/ros2_ws
colcon build --packages-select serial
source install/setup.bash
```

---

## 📄 API & Features

* Standard PySerial-like modern C++ API (`open()`, `close()`, `read()`, `write()`, `readline()`).
* Tight control over byte timeouts and control lines (RTS, CTS, DTR, DSR).
* Zero external third-party dependencies required.

---

## 📜 License & Original Authors
* **Author**: William Woodall (<william@osrfoundation.org>), John Harrison
* **License**: MIT License

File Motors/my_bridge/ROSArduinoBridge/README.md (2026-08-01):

# Arduino Motor Controller

This code turns an Arduino into a motor controller!
It provides a simple serial interface to communicate with a high-level computer (e.g. running ROS), and generates the appropriate PWM signals for a motor driver, to drive two motors.

This is a fork of the original code, with some changes, and removal of the ROS nodes (see [this repo](https://github.com/joshnewans/serial_motor_demo) for an alternative). Check out `README-orig.md` for the original README.

As I only have need for a subset of the functionality, I have no idea what does and doesn't work, beyond what is detailed below.
Feedback/improvements are welcome (though no promises on how quickly I'll respond). I currently only use the **Cytron MDD10A** driver, and the Arduino encoder mode.

TODO
- Finish this README

## Hardware: Cytron MDD10A wiring

This fork is configured for an Arduino Nano + Cytron MDD10A dual motor driver, using the MDD10A's **PWM/DIR** mode (the driver's factory-default mode; make sure the onboard mode switch is set to PWM, not IN1/IN2).

Default pin mapping (edit in `motor_driver.h` if yours differs):

| Signal | Arduino Nano pin | MDD10A pin |
|---|---|---|
| Left DIR | D7 | M1DIR |
| Left PWM | D10 | M1PWM |
| Right DIR | D8 | M2DIR |
| Right PWM | D9 | M2PWM |

The MDD10A's `EN` pin can simply be tied to +5V (recommended, saves a pin). If you'd rather drive it from the Arduino, wire it to a spare pin and uncomment/set `MOTOR_DRIVER_ENABLE_PIN` in `motor_driver.h`.

If a motor spins the wrong direction, don't rewire the driver — just flip the `reverse == 0 / 1` logic for that motor in `motor_driver.ino`.

Encoders are still wired directly to the Arduino as before (`ARDUINO_ENC_COUNTER` mode): D2/D3 for left, A4/A5 for right.

## Functionality

The main functionality provided is to receive motor speed requests over a serial connection, and provide encoder feedback.
The original code has provisions for other features - e.g. read/write of digital/analog pins, servo control, but I've never used them.

The main commands to know are

- `e` - Motor responds with current encoder counts for each motor
- `r` - Reset encoder values
- `o <PWM1> <PWM2>` - Set the raw PWM speed of each motor (-255 to 255)
- `m <Spd1> <Spd2>` - Set the closed-loop speed of each motor in *counts per loop* (Default loop rate is 30, so `(counts per sec)/30`
- `p <Kp> <Kd> <Ki> <Ko>` - Update the PID parameters

## Gotchas

Some quick things to note

- There is an auto timeout (default 2s) so you need to keep sending commands for it to keep moving
- PID parameter order is PDI (?)
- Motor speed is in counts per loop
- Default baud rate 57600
- Needs carriage return (CR)
- Make sure serial is enabled (user in dialout group)
- Check out the original readme for more

## TODO (maybe)
- Document PID tuning
- Make the speed input counts per second
- Add/test more driver boards
- Add/test other functionality

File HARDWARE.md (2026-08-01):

# Hardware Overview

This document provides a complete overview of the hardware used in the **Warehouse Stock Navigation Robot**. The robot is designed as an autonomous mobile robot (AMR) capable of warehouse mapping, localization, navigation, live monitoring, and future inventory management.

---

# System Architecture

The robot consists of the following major subsystems:

* Computing Unit
* Navigation Sensors
* Motion System
* Vision System
* Motor Control
* Power Distribution
* Communication Interfaces

---

# Hardware Specifications

| Component | Quantity | Purpose |
| --- | ---: | --- |
| Raspberry Pi 4 (4GB RAM) | 1 | Main onboard computer running ROS2 |
| RPLidar A1M8 (12m, 360°) | 1 | Mapping, localization, obstacle detection |
| Arduino Nano | 1 | Motor control, encoder processing |
| TTN25 Encoder DC Gear Motors (12V, 370 RPM) | 2 | Differential drive locomotion |
| Cytron MDD10A Dual Channel Motor Driver | 1 | Drives left and right motors |
| ESP32-CAM | 1 | Live video streaming |
| ESP32 Development Board | 1 | Camera gimbal controller |
| PCA9685 Servo Driver | 1 | Servo PWM generation |
| SG90 Servo Motor | 2 | Camera yaw and pitch control |
| Buck Converter | 1 | Voltage regulation |
| Power Distribution Board | 1 | Power distribution |
| Battery Pack | 1 | Primary power source |
| Chassis | 1 | Robot frame |

---

# Computing Unit

## Raspberry Pi 4

**Specifications**

* RAM: 4 GB
* Operating System: Ubuntu 22.04 LTS
* ROS2 Distribution: Humble Hawksbill

### Responsibilities

* Runs ROS2
* Navigation2 Stack
* SLAM Toolbox
* AMCL Localization
* RPLidar Driver
* Path Planning
* Obstacle Avoidance
* ESP32 Camera Stream
* Serial Communication with Arduino

---

# Navigation Sensor

## RPLidar A1M8

### Specifications

* 360° Laser Scanner
* Maximum Range: 12 meters
* USB Communication
* 2D LiDAR

### Purpose

* Environment Mapping
* Localization
* Obstacle Detection
* Costmap Generation
* Autonomous Navigation

ROS Topic

```
/scan
```

---

# Motion System

## Drive Configuration

* Differential Drive Robot

### Motors

**TTN25 Encoder Gear Motors**

Quantity

```
2
```

Specifications

* Operating Voltage: 12V
* Speed: 370 RPM
* Integrated Quadrature Encoder

Functions

* Robot locomotion
* Closed-loop velocity control
* Wheel odometry

---

# Motor Driver

## Cytron MDD10A

Specifications

* Dual Channel
* 10A Continuous Current
* PWM + Direction Interface

Purpose

* Controls left motor
* Controls right motor
* Receives PWM signals from Arduino Nano

---

# Embedded Controller

## Arduino Nano

### Responsibilities

* Reads wheel encoders
* Calculates wheel velocity
* PID motor control
* Receives velocity commands
* Sends odometry to Raspberry Pi
* Controls MDD10A

Communication

```
USB Serial
```

---

# Vision System

## ESP32-CAM

Purpose

* Live video streaming
* Warehouse monitoring
* Shelf inspection
* Future barcode detection
* Future QR code detection
* Future object detection

Communication

```
Wi-Fi
```

---

# Camera Gimbal

The camera is mounted on a custom-built two-axis gimbal.

Components

* ESP32
* PCA9685 Servo Driver
* SG90 Servo (Yaw)
* SG90 Servo (Pitch)

Capabilities

* Horizontal rotation
* Vertical rotation
* Shelf inspection
* Remote camera control

---

# Servo Driver

## PCA9685

Purpose

* 16-channel PWM controller
* Drives both SG90 servos
* Controlled using I²C

---

# Power System

## Battery

Provides power to

* Raspberry Pi
* Arduino Nano
* Motor Driver
* Motors
* ESP32
* Servo Driver

---

## Power Distribution Board

Purpose

* Safe power distribution
* Organized wiring
* Multiple voltage outputs

---

## Buck Converter

Purpose

Converts battery voltage into regulated outputs for

* Raspberry Pi
* Arduino Nano
* ESP32
* PCA9685
* Servo System

---

# Communication Interfaces

| Interface | Devices |
| --- | --- |
| USB | Raspberry Pi ↔ RPLidar |
| USB Serial | Raspberry Pi ↔ Arduino Nano |
| Wi-Fi | Raspberry Pi ↔ ESP32-CAM |
| I²C | ESP32 ↔ PCA9685 |
| PWM | PCA9685 ↔ SG90 Servos |
| PWM + Direction | Arduino ↔ MDD10A |

---

# Software-Hardware Mapping

| Hardware | Software |
| --- | --- |
| Raspberry Pi | ROS2 Humble |
| RPLidar | rplidar_ros |
| Arduino Nano | Motor Control Firmware |
| Encoders | Wheel Odometry |
| Differential Drive | ros2_control |
| ESP32-CAM | Live Video Streaming |
| Navigation | Navigation2 |
| Mapping | SLAM Toolbox |
| Localization | AMCL |

---

# Robot Features

* Autonomous SLAM mapping
* Autonomous localization
* Autonomous navigation
* Obstacle avoidance
* Differential drive motion
* Wheel encoder odometry
* Closed-loop motor control
* Live Wi-Fi camera feed
* Two-axis camera gimbal
* Shelf inspection
* Expandable hardware architecture

---

# Future Hardware Upgrades

* IMU (BNO055/BNO085)
* Battery Management System (BMS)
* Charging Dock
* QR/Barcode Scanner
* RGB-D Camera
* Industrial Emergency Stop
* Status LEDs and Buzzer
* Environmental Sensors
* Higher resolution camera
* AI accelerator (Google Coral TPU or Intel Neural Compute Stick)

---

# Overall Hardware Architecture

```text
                   +-----------------------------+
                   |      Raspberry Pi 4         |
                   |-----------------------------|
                   | ROS2 Humble                 |
                   | Navigation2                 |
                   | SLAM Toolbox                |
                   | AMCL                        |
                   +-------------+---------------+
                                 |
                    USB Serial
                                 |
                          Arduino Nano
                +----------------+----------------+
                |                                 |
          Encoder Feedback                 MDD10A Driver
                |                                 |
        Left / Right Encoders          Left / Right Motors

RPLidar A1M8 -------- USB --------> Raspberry Pi

ESP32-CAM ---------- Wi-Fi -------> Raspberry Pi

ESP32 ---- I²C ----> PCA9685 ----> SG90 (Yaw)

                               └──> SG90 (Pitch)

Battery
   │
   ├── Power Distribution Board
   │
   ├── Buck Converter
   │
   ├── Raspberry Pi
   ├── Arduino Nano
   ├── ESP32
   ├── PCA9685
   └── Motor Driver
```

---

# Hardware Summary

The Warehouse Stock Navigation Robot is built around a modular ROS2 architecture using a Raspberry Pi 4 as the main computing platform. It combines LiDAR-based autonomous navigation, encoder-based odometry, differential drive control, and a Wi-Fi-enabled pan-tilt camera system. The modular design allows future integration of AI-based inventory management, barcode/QR scanning, autonomous charging, and advanced perception sensors, making it suitable for research, education, and warehouse automation applications.

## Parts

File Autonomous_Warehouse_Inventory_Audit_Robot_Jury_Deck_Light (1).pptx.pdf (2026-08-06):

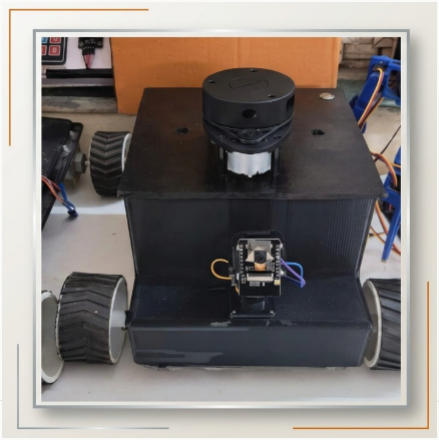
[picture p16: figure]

WAREOP S

# Autonomous Warehouse Inventory Audit Robot (WAREOps)

An autonomous mobile robot that patrols warehouse aisles, inspects shelves with computer vision, and continuously verifies inventory — closing the gap between what the system records and what is physically on the shelf.

LiDAR Mapping | | Autonomous Navigation | | Camera-Gimbal Inspection
W A R E O P S | 01

TEAM MEMBERS
Abhinav Goel · Aanshu Kashyap · Alok Kumar Mishra · Utkarsh Kumar · Anshuman Singh

PROJECT GUIDE

## Prof. Prabin Kumar Padhy

DEPARTMENT / INSTITUTION

### Electronics & Communication Engineering

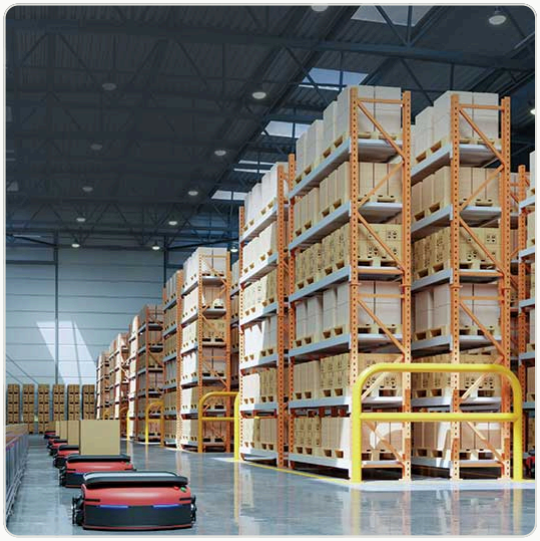
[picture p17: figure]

# Warehousing Is Entering a New Era

Rapid growth in e-commerce and omnichannel retail has redefined warehouse operations. Fulfillment centers now move millions of items daily across thousands of SKUs, while delivery windows have compressed from days to hours.

Warehouses are becoming increasingly automated — but automation alone does not guarantee inventory visibility.

W A R E O P S | 02

SECTION 1 — INDUSTRY CONTEXT

INDUSTRY GROWTH

# Industry Leaders Are Investing at Scale

Warehouse automation has become one of the fastest-growing categories in industrial technology.

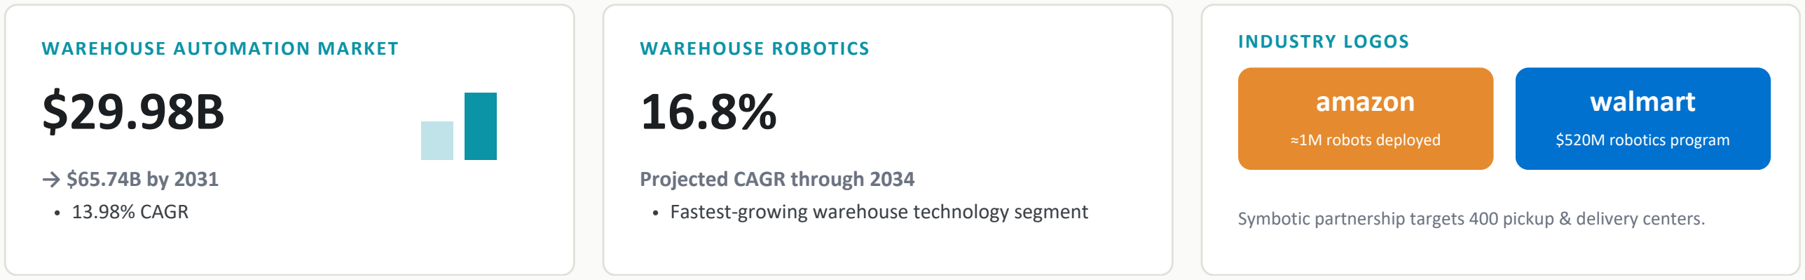
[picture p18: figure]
WAREHOUSE AUTOMATION MARKET $29.98B; 13.98% CAGR; WAREHOUSE ROBOTICS 16.8%; Projected CAGR through 2034; Fastest-growing warehouse technology segment; INDUSTRY LOGOS; amazon; ≈1M robots deployed; walmart; $520M robotics program

Symbotic partnership targets 400 pickup & delivery centers.

At scale, more inventory is moving through automated systems than ever before — raising the stakes for accuracy.

Warehouses are becoming increasingly automated — but automation alone does not guarantee inventory visibility.

W A R E O P S | 03

F INANCIAL & OPERATIONAL IMPACT

# The Cost of Poor Inventory Visibility

Why should we care about inventory accuracy?

FINANCIAL IMPACT

# $90–100B+ / year

U.S. retail inventory shrink from theft, operational errors, damage, and inaccuracies.

Walmart example ≈$681B annual revenue. A 1% inventory loss ≈ $6.8B potential impact.

OPERATIONAL IMPACT

Lost sales | Delayed shipments
Longer search times | Manual rework
Reduced productivity | Customer dissatisfaction

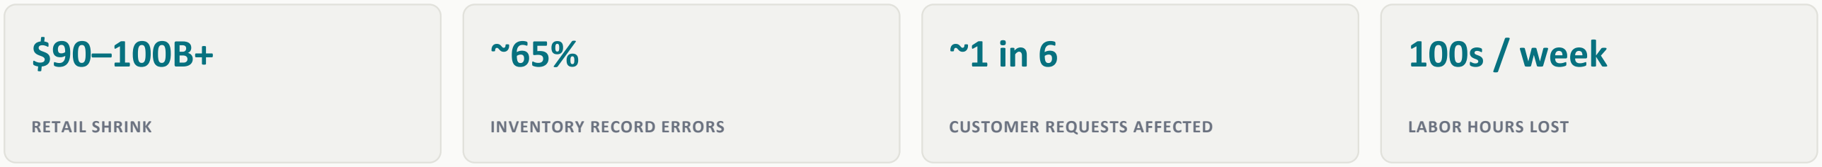
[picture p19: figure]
RETAIL SHRINK; INVENTORY RECORD ERRORS; CUSTOMER REQUESTS AFFECTED; 100s / week; LABOR HOURS LOST

Inventory inaccuracies cost far more than the missing product — they disrupt the entire supply chain.

Figures reflect U.S. retail field studies; used for directional context.

W A R E O P S | 04

OPERATIONAL BREAKDOWN

# Why Does Inventory Become Invisible?

How do these losses actually occur?

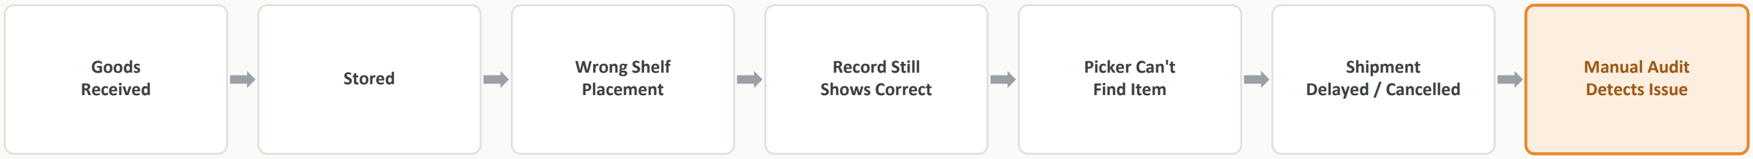
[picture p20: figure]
Goods; Received; Stored; Wrong Shelf; Placement; Record Still Shows Correct; Picker Can't Find Item; Shipment Delayed / Cancelled; Manual Audit Detects Issue

IMPACT ACCUMULATES ACROSS | ⏱ | Time | $ | Money | ▣ | Stock | 👷 | Labor | ♥ | Trust

A misplaced product is often physically present — but operationally invisible.

Downstream cost compounds silently: what starts as a shelf error ends as a cancelled order and an audit finding it too late.

W A R E O P S | 05

APPROACH COMPARISON

# Why Existing Approaches Still Leave a Gap

If companies invest so much, why does this still happen?

| EXISTING APPROACH | PRIMARY STRENGTH | WHY MISPLACEMENT PERSISTS
📋 | Manual Audits | Low setup cost | Periodic, labor-intensive, not real-time
▦ | Barcode / QR | Accurate identification | Requires manual scanning
)) | RFID | Faster tracking | High infrastructure and tag cost
📷 | Fixed Cameras | Continuous observation | Blind spots, occlusion, limited viewpoints
🤖 | Warehouse Robots | Material movement | Optimized for transport, not continuous auditing

Today's automation focuses on: ✔ Transporting ✔ Picking ✔ Sorting
…rather than: ✘ Continuously verifying correct storage location

The challenge is no longer moving inventory — it is maintaining continuous visibility of inventory.

W A R E O P S | 06

POSITIONING

# The Missing Layer in Warehouse Automation

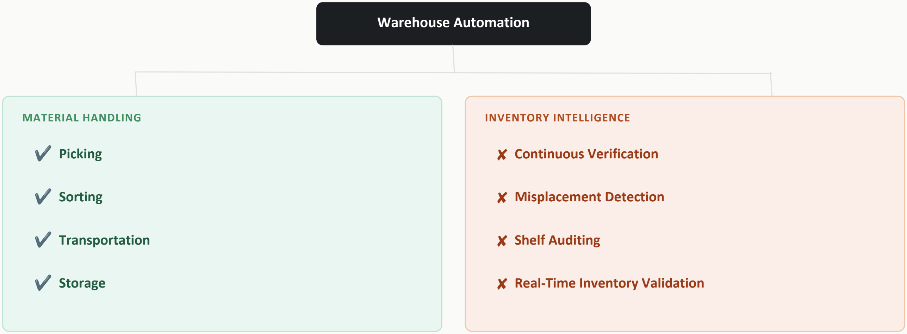
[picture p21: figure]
Warehouse Automation; MATERIAL HANDLING; ✔ Picking; ✔ Sorting; ✔ Transportation; ✔ Storage; INVENTORY INTELLIGENCE; ✘ Continuous Verification; ✘ Misplacement Detection; ✘ Shelf Auditing; ✘ Real-Time Inventory Validation

Current automation moves products efficiently. Inventory verification still depends on manual inspections and reactive discovery.

This is the operational gap our project addresses.

W A R E O P S | 07

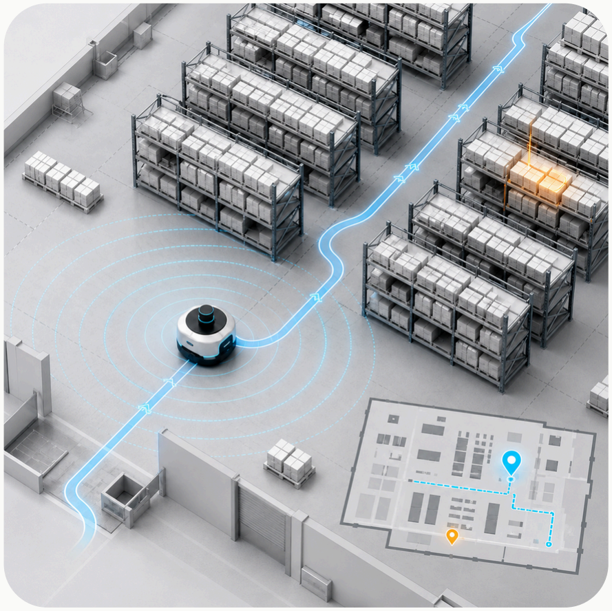
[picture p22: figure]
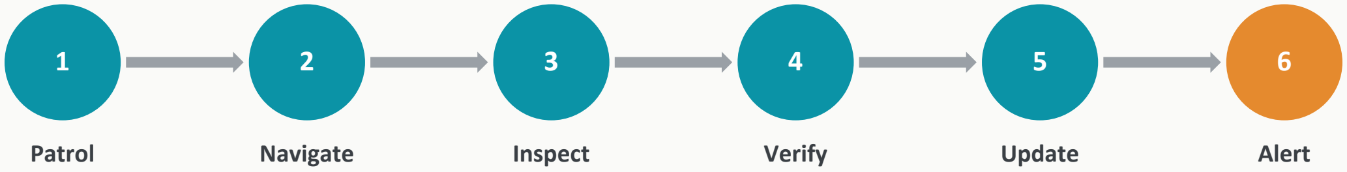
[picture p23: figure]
Patrol; Navigate; Inspect; Verify; Update; Alert

No warehouse redesign. No dense camera network. No RFID infrastructure. Just continuous inventory visibility.

W A R E O P S | 08

SECTION 2 — THE SOLUTION

# Our Autonomous Inventory Auditing Robot

Navigates warehouse aisles (ROS2 + SLAM)

Inspects shelves using computer vision

Reads QR codes at each location

Detects misplaced inventory

Updates inventory records automatically

Alerts operators in real time

Supports FIFO / FEFO compliance

PROJECTED IMPACT

# Expected Operational Impact

What changes for the warehouse after deployment.

BEFORE | AFTER
Periodic manual audits | Continuous autonomous auditing
Inventory searched manually | Inventory verified continuously
Delayed discrepancy detection | Real-time alerts
Reactive corrections | Preventive monitoring
Higher labor dependency | Reduced manual effort
Limited inventory visibility | Continuous inventory intelligence

Our solution complements existing warehouse automation — adding the missing layer of continuous inventory intelligence, so warehouses know not only where products should be, but where they actually are.

W A R E O P S | 09

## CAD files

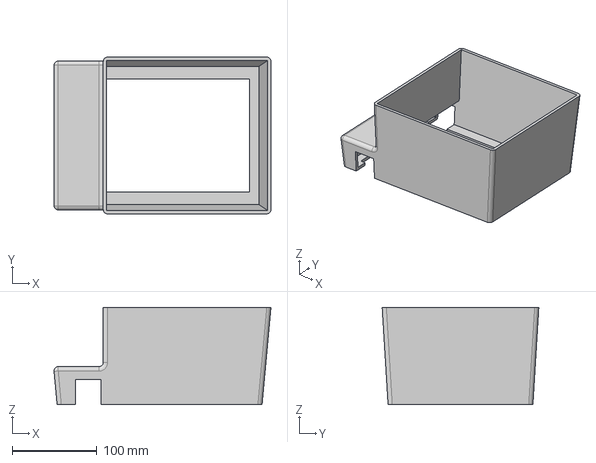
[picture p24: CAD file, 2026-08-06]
Chassis_step_file/WareOps_BOT.step
256.1 x 185.0 x 115.0 mm

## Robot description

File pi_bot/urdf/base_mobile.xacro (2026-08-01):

<?xml version="1.0"?>
<robot xmlns:xacro="http://www.ros.org/wiki/xacro" >

    <xacro:property name="base_length" value="0.263"/>
    <xacro:property name="base_width" value="0.1635"/>
    <xacro:property name="base_height" value="0.12"/>
    <xacro:property name="base_mass" value="1.671"/>

    <xacro:property name="wheel_radius" value="0.035"/>
    <xacro:property name="wheel_length" value="0.04"/>
    <xacro:property name="wheel_mass" value="0.055"/>

    <xacro:property name="caster_wheel_radius" value="0.0175"/>
    <xacro:property name="caster_wheel_mass" value="0.020"/>
 

    <xacro:macro name="cuboid_link" params="prefix m l b h x y z r p yaw " >
        <link name="${prefix}_link">
            <visual>
                <geometry>
                    <box size="${l} ${b} ${h}"/>
                </geometry>
                <origin xyz="${x} ${y} ${z}" rpy="${r} ${p} ${yaw}"/>
                <material name="green"/>
            </visual>
            <xacro:cuboid_collision lbh="${l} ${b} ${h}" o_xyz="${x} ${y} ${z}" o_rpy="${r} ${p} ${yaw}"/>
            <xacro:cuboid_inertia m="${m}" l="${l}" b="${b}" h="${h}" o_xyz="${x} ${y} ${z}" o_rpy="${r} ${p} ${yaw}"/>
        </link>
    </xacro:macro>

    <xacro:macro name="cube_link" params="prefix m l b h x y z r p yaw " >
        <link name="${prefix}_link">
            <visual>
                <geometry>
                    <box size="${l} ${b} ${h}"/>
                </geometry>
                <origin xyz="${x} ${y} ${z}" rpy="${r} ${p} ${yaw}"/>
                <material name="red"/>
            </visual>
            <xacro:cuboid_collision lbh="${l} ${b} ${h}" o_xyz="${x} ${y} ${z}" o_rpy="${r} ${p} ${yaw}"/>
            <xacro:cuboid_inertia m="${m}" l="${l}" b="${b}" h="${h}" o_xyz="${x} ${y} ${z}" o_rpy="${r} ${p} ${yaw}"/>
        </link>
    </xacro:macro>

    <xacro:macro name="small_cuboid_link" params="prefix m l b h x y z r p yaw " >
        <link name="${prefix}_link">
            <visual>
                <geometry>
                    <box size="${l} ${b} ${h}"/>
                </geometry>
                <origin xyz="${x} ${y} ${z}" rpy="${r} ${p} ${yaw}"/>
                <material name="grey"/>
            </visual>
            <xacro:cuboid_collision lbh="${l} ${b} ${h}" o_xyz="${x} ${y} ${z}" o_rpy="${r} ${p} ${yaw}"/>
            <xacro:cuboid_inertia m="${m}" l="${l}" b="${b}" h="${h}" o_xyz="${x} ${y} ${z}" o_rpy="${r} ${p} ${yaw}"/>
        </link>
    </xacro:macro>


    <xacro:macro name="wheel_link" params="prefix m r l x y z roll p yaw">
        <link name="${prefix}_wheel_link">
            <visual>
                <geometry>
                    <cylinder radius="${r}" length="${l}"/>
                </geometry>
                <origin xyz="${x} ${y} ${z}" rpy="${roll} ${p} ${yaw}"/>
                <material name="blue"/>
            </visual>
            <xacro:cylinder_inertia m="${m}" r="${r}" l="${l}" o_xyz="${x} ${y} ${z}" o_rpy="${roll} ${p} ${yaw}"/>
            <collision>
                <geometry>
                    <sphere radius="${r}"/>
                </geometry>
            </collision>
        </link>
    </xacro:macro>


    <xacro:macro name="sphere_link" params="prefix m r x y z roll p yaw">
        <link name="${prefix}_sphere_link">
            <visual>
                <geometry>
                    <sphere radius="${r}"/>
                </geometry>
                <origin xyz="${x} ${y} ${z}" rpy="${roll} ${p} ${yaw}"/>
                <material name="yellow"/>
            </visual>
            <xacro:sphere_inertia m="${m}" r="${r}" o_xyz="${x} ${y} ${z}" o_rpy="${roll} ${p} ${yaw}"/>
            <xacro:sphere_collision r="${r}" o_xyz="${x} ${y} ${z}" o_rpy="${roll} ${p} ${yaw}"/>
        </link>
    </xacro:macro>


    <link name="odom"/>
    <joint name="odom_to_base_footprint" type="fixed">
        <parent link="odom"/>
        <child link="base_footprint"/>
        <origin xyz="0 0 0" rpy="0 0 0"/>
    </joint>
 
    
    
    
    <link name="base_footprint"/>

    <xacro:cuboid_link prefix="base" m="${base_mass}" l="${base_length}" b="${base_width}" h="${base_height}" x="0" y="0" z="${base_height/2}" r="0" p="0" yaw="0"/>

    <xacro:wheel_link prefix="front_right" m="${wheel_mass}" l="${wheel_length}" r="${wheel_radius}" x="0" y="0" z="0" roll="${pi/2}" p="0" yaw="0"/>

    <xacro:wheel_link prefix="front_left" m="${wheel_mass}" l="${wheel_length}" r="${wheel_radius}" x="0" y="0" z="0" roll="${pi/2}" p="0" yaw="0"/>

    <xacro:sphere_link prefix="rear_caster" m="${caster_wheel_mass}" r="${caster_wheel_radius}" x="0" y="0" z="0" roll="0" p="0" yaw="0"/>




    <joint name="base_footprint_base_joint" type="fixed">
        <parent link="base_footprint"/>
        <child link="base_link"/>
        <origin xyz="0 0 0.0175" rpy="0 0 0"/>
    </joint>



    <joint name="base_front_right_wheel_joint" type="continuous">
        <parent link="base_link"/>
        <child link="front_right_wheel_link"/>
        <axis xyz="0 1 0"/>        
        <origin xyz="0.090391 ${-((0.171/2)+(wheel_length/2)+0.01125)} 0.0175" rpy="0 0 0"/>
    </joint>

    <joint name="base_front_left_wheel_joint" type="continuous">
        <parent link="base_link"/>
        <child link="front_left_wheel_link"/>
        <axis xyz="0 1 0"/>        
        <origin xyz="0.090391 ${((0.171/2)+(wheel_length/2)+0.01125)} 0.0175" rpy="0 0 0"/>
    </joint>

    <joint name="base_rear_caster_wheel_joint" type="fixed">
        <parent link="base_link"/>
        <child link="rear_caster_sphere_link"/>
        <origin xyz="-0.0655 0 0" rpy="0 0 0"/> 
    </joint>

    <gazebo reference="rear_caster_sphere_link">
        <mu1 value="0.001"/>
        <mu2 value="0.001"/>
    </gazebo>


    <xacro:cube_link prefix="scan" m="0.186" l="0.0605" b="0.069" h="0.055" x="0" y="0" z="-0.0175" r="0" p="0" yaw="0"/>


    <joint name="scan_joint" type="fixed">
        <origin xyz="0.0 0 ${0.12+0.045}" rpy="0 0 0"/>
        <child link="scan_link"/> 
        <parent link="base_link"/> 
    </joint>



</robot>

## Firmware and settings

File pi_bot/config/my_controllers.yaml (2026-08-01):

controller_manager:
  ros__parameters:
    update_rate: 30
    # use_sim_time: true

    diff_cont:
      type: diff_drive_controller/DiffDriveController

    joint_broad:
      type: joint_state_broadcaster/JointStateBroadcaster

diff_cont:
  ros__parameters:

    publish_rate: 50.0

    base_frame_id: base_footprint

    left_wheel_names: ['base_front_left_wheel_joint']
    right_wheel_names: ['base_front_right_wheel_joint']
    wheel_separation: 0.2335
    wheel_radius: 0.035

    use_stamped_vel: false

    # open_loop: false    

    # wheels_per_side: x
    # wheel_separation_multiplier: x
    # left_wheel_radius_multiplier: x
    # right_wheel_radius_multiplier: x

    # odom_frame_id: x
    # pose_covariance_diagonal: x
    # twist_covariance_diagonal: x
    # open_loop: x
    # enable_odom_tf: x

    # cmd_vel_timeout: x
    # publish_limited_velocity: x
    # velocity_rolling_window_size: x
    

    # linear.x.has_velocity_limits: false
    # linear.x.has_acceleration_limits: false
    # linear.x.has_jerk_limits: false
    # linear.x.max_velocity: NAN
    # linear.x.min_velocity: NAN
    # linear.x.max_acceleration: NAN
    # linear.x.min_acceleration: NAN
    # linear.x.max_jerk: NAN
    # linear.x.min_jerk: NAN

    # angular.z.has_velocity_limits: false
    # angular.z.has_acceleration_limits: false
    # angular.z.has_jerk_limits: false
    # angular.z.max_velocity: NAN
    # angular.z.min_velocity: NAN
    # angular.z.max_acceleration: NAN
    # angular.z.min_acceleration: NAN
    # angular.z.max_jerk: NAN
    # angular.z.min_jerk: NAN




# joint_broad:
#   ros__parameters:

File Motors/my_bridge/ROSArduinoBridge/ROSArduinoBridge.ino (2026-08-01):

/*********************************************************************
 *  ROSArduinoBridge
 
    A set of simple serial commands to control a differential drive
    robot and receive back sensor and odometry data. Default 
    configuration assumes use of an Arduino Mega + Pololu motor
    controller shield + Robogaia Mega Encoder shield.  Edit the
    readEncoder() and setMotorSpeed() wrapper functions if using 
    different motor controller or encoder method.

    Created for the Pi Robot Project: http://www.pirobot.org
    and the Home Brew Robotics Club (HBRC): http://hbrobotics.org
    
    Authors: Patrick Goebel, James Nugen

    Inspired and modeled after the ArbotiX driver by Michael Ferguson
    
    Software License Agreement (BSD License)

    Copyright (c) 2012, Patrick Goebel.
    All rights reserved.

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
    THIS SOFTWARE IS PROVIDED BY THE COPYRIGHT HOLDERS AND CONTRIBUTORS
    "AS IS" AND ANY EXPRESS OR IMPLIED WARRANTIES, INCLUDING, BUT NOT
    LIMITED TO, THE IMPLIED WARRANTIES OF MERCHANTABILITY AND FITNESS
    FOR A PARTICULAR PURPOSE ARE DISCLAIMED. IN NO EVENT SHALL THE
    COPYRIGHT OWNER OR CONTRIBUTORS BE LIABLE FOR ANY DIRECT, INDIRECT,
    INCIDENTAL, SPECIAL, EXEMPLARY, OR CONSEQUENTIAL DAMAGES (INCLUDING,
    BUT NOT LIMITED TO, PROCUREMENT OF SUBSTITUTE GOODS OR SERVICES;
    LOSS OF USE, DATA, OR PROFITS; OR BUSINESS INTERRUPTION) HOWEVER
    CAUSED AND ON ANY THEORY OF LIABILITY, WHETHER IN CONTRACT, STRICT
    LIABILITY, OR TORT (INCLUDING NEGLIGENCE OR OTHERWISE) ARISING IN
    ANY WAY OUT OF THE USE OF THIS SOFTWARE, EVEN IF ADVISED OF THE
 *  POSSIBILITY OF SUCH DAMAGE.
 *********************************************************************/

#define USE_BASE      // Enable the base controller code
//#undef USE_BASE     // Disable the base controller code

/* Define the motor controller and encoder library you are using */
#ifdef USE_BASE
   /* The Pololu VNH5019 dual motor driver shield */
   //#define POLOLU_VNH5019

   /* The Pololu MC33926 dual motor driver shield */
   //#define POLOLU_MC33926

   /* The RoboGaia encoder shield */
   //#define ROBOGAIA
   
   /* Encoders directly attached to Arduino board */
   #define ARDUINO_ENC_COUNTER

   /* L298 Motor driver*/
   //#define L298_MOTOR_DRIVER

   /* Cytron MDD10A Dual Channel 10A Motor Driver (PWM/DIR mode) */
   #define CYTRON_MDD10A
#endif

//#define USE_SERVOS  // Enable use of PWM servos as defined in servos.h
#undef USE_SERVOS     // Disable use of PWM servos

/* Serial port baud rate */
#define BAUDRATE     57600

/* Maximum PWM signal */
#define MAX_PWM        255

#if defined(ARDUINO) && ARDUINO >= 100
#include "Arduino.h"
#else
#include "WProgram.h"
#endif

/* Include definition of serial commands */
#include "commands.h"

/* Sensor functions */
#include "sensors.h"

/* Include servo support if required */
#ifdef USE_SERVOS
   #include <Servo.h>
   #include "servos.h"
#endif

#ifdef USE_BASE
  /* Motor driver function definitions */
  #include "motor_driver.h"

  /* Encoder driver function definitions */
  #include "encoder_driver.h"

  /* PID parameters and functions */
  #include "diff_controller.h"

  /* Run the PID loop at 30 times per second */
  #define PID_RATE           30     // Hz

  /* Convert the rate into an interval */
  const int PID_INTERVAL = 1000 / PID_RATE;
  
  /* Track the next time we make a PID calculation */
  unsigned long nextPID = PID_INTERVAL;

  /* Stop the robot if it hasn't received a movement command
   in this number of milliseconds */
  #define AUTO_STOP_INTERVAL 2000
  long lastMotorCommand = AUTO_STOP_INTERVAL;
#endif

/* Variable initialization */

// A pair of varibles to help parse serial commands (thanks Fergs)
int arg = 0;
int index = 0;

// Variable to hold an input character
char chr;

// Variable to hold the current single-character command
char cmd;

// Character arrays to hold the first and second arguments
char argv1[16];
char argv2[16];

// The arguments converted to integers
long arg1;
long arg2;

/* Clear the current command parameters */
void resetCommand() {
  cmd = NULL;
  memset(argv1, 0, sizeof(argv1));
  memset(argv2, 0, sizeof(argv2));
  arg1 = 0;
  arg2 = 0;
  arg = 0;
  index = 0;
}

/* Run a command.  Commands are defined in commands.h */
int runCommand() {
  int i = 0;
  char *p = argv1;
  char *str;
  int pid_args[4];
  arg1 = atoi(argv1);
  arg2 = atoi(argv2);
  
  switch(cmd) {
  case GET_BAUDRATE:
    Serial.println(BAUDRATE);
    break;
  case ANALOG_READ:
    Serial.println(analogRead(arg1));
    break;
  case DIGITAL_READ:
    Serial.println(digitalRead(arg1));
    break;
  case ANALOG_WRITE:
    analogWrite(arg1, arg2);
    Serial.println("OK"); 
    break;
  case DIGITAL_WRITE:
    if (arg2 == 0) digitalWrite(arg1, LOW);
    else if (arg2 == 1) digitalWrite(arg1, HIGH);
    Serial.println("OK"); 
    break;
  case PIN_MODE:
    if (arg2 == 0) pinMode(arg1, INPUT);
    else if (arg2 == 1) pinMode(arg1, OUTPUT);
    Serial.println("OK");
    break;
  case PING:
    Serial.println(Ping(arg1));
    break;
#ifdef USE_SERVOS
  case SERVO_WRITE:
    servos[arg1].setTargetPosition(arg2);
    Serial.println("OK");
    break;
  case SERVO_READ:
    Serial.println(servos[arg1].getServo().read());
    break;
#endif
    
#ifdef USE_BASE
  case READ_ENCODERS:
    Serial.print(readEncoder(LEFT));
    Serial.print(" ");
    Serial.println(readEncoder(RIGHT));
    break;
   case RESET_ENCODERS:
    resetEncoders();
    resetPID();
    Serial.println("OK");
    break;
  case MOTOR_SPEEDS:
    /* Reset the auto stop timer */
    lastMotorCommand = millis();
    if (arg1 == 0 && arg2 == 0) {
      setMotorSpeeds(0, 0);
      resetPID();
      moving = 0;
    }
    else moving = 1;
    leftPID.TargetTicksPerFrame = arg1;
    rightPID.TargetTicksPerFrame = arg2;
    Serial.println("OK"); 
    break;
  case MOTOR_RAW_PWM:
    /* Reset the auto stop timer */
    lastMotorCommand = millis();
    resetPID();
    moving = 0; // Sneaky way to temporarily disable the PID
    setMotorSpeeds(arg1, arg2);
    Serial.println("OK"); 
    break;
  case UPDATE_PID:
    while ((str = strtok_r(p, ":", &p)) != '\0') {
       pid_args[i] = atoi(str);
       i++;
    }
    Kp = pid_args[0];
    Kd = pid_args[1];
    Ki = pid_args[2];
    Ko = pid_args[3];
    Serial.println("OK");
    break;
#endif
  default:
    Serial.println("Invalid Command");
    break;
  }
}

/* Setup function--runs once at startup. */
void setup() {
  Serial.begin(BAUDRATE);

// Initialize the motor controller if used */
#ifdef USE_BASE
  #ifdef ARDUINO_ENC_COUNTER
    //set as inputs
    DDRD &= ~(1<<LEFT_ENC_PIN_A);
    DDRD &= ~(1<<LEFT_ENC_PIN_B);
    DDRC &= ~(1<<RIGHT_ENC_PIN_A);
    DDRC &= ~(1<<RIGHT_ENC_PIN_B);
    
    //enable pull up resistors
    PORTD |= (1<<LEFT_ENC_PIN_A);
    PORTD |= (1<<LEFT_ENC_PIN_B);
    PORTC |= (1<<RIGHT_ENC_PIN_A);
    PORTC |= (1<<RIGHT_ENC_PIN_B);
    
    // tell pin change mask to listen to left encoder pins
    PCMSK2 |= (1 << LEFT_ENC_PIN_A)|(1 << LEFT_ENC_PIN_B);
    // tell pin change mask to listen to right encoder pins
    PCMSK1 |= (1 << RIGHT_ENC_PIN_A)|(1 << RIGHT_ENC_PIN_B);
    
    // enable PCINT1 and PCINT2 interrupt in the general interrupt mask
    PCICR |= (1 << PCIE1) | (1 << PCIE2);
  #endif
  initMotorController();
  resetPID();
#endif

/* Attach servos if used */
  #ifdef USE_SERVOS
    int i;
    for (i = 0; i < N_SERVOS; i++) {
      servos[i].initServo(
          servoPins[i],
          stepDelay[i],
          servoInitPosition[i]);
    }
  #endif
}

/* Enter the main loop.  Read and parse input from the serial port
   and run any valid commands. Run a PID calculation at the target
   interval and check for auto-stop conditions.
*/
void loop() {
  while (Serial.available() > 0) {
    
    // Read the next character
    chr = Serial.read();

    // Terminate a command with a CR
    if (chr == 13) {
      if (arg == 1) argv1[index] = NULL;
      else if (arg == 2) argv2[index] = NULL;
      runCommand();
      resetCommand();
    }
    // Use spaces to delimit parts of the command
    else if (chr == ' ') {
      // Step through the arguments
      if (arg == 0) arg = 1;
      else if (arg == 1)  {
        argv1[index] = NULL;
        arg = 2;
        index = 0;
      }
      continue;
    }
    else {
      if (arg == 0) {
        // The first arg is the single-letter command
        cmd = chr;
      }
      else if (arg == 1) {
        // Subsequent arguments can be more than one character
        argv1[index] = chr;
        index++;
      }
      else if (arg == 2) {
        argv2[index] = chr;
        index++;
      }
    }
  }
  
// If we are using base control, run a PID calculation at the appropriate intervals
#ifdef USE_BASE
  if (millis() > nextPID) {
    updatePID();
    nextPID += PID_INTERVAL;
  }
  
  // Check to see if we have exceeded the auto-stop interval
  if ((millis() - lastMotorCommand) > AUTO_STOP_INTERVAL) {;
    setMotorSpeeds(0, 0);
    moving = 0;
  }
#endif

// Sweep servos
#ifdef USE_SERVOS
  int i;
  for (i = 0; i < N_SERVOS; i++) {
    servos[i].doSweep();
  }
#endif
}

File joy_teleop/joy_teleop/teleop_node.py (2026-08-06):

#!/usr/bin/env python3

import rclpy
from rclpy.node import Node

from sensor_msgs.msg import Joy
from geometry_msgs.msg import Twist
from std_msgs.msg import String
import json
import subprocess


class PS2Teleop(Node):

    def __init__(self):
        super().__init__('ps2_teleop')

        self.subscription = self.create_subscription(
            Joy,
            '/joy',
            self.joy_callback,
            10)

        self.publisher = self.create_publisher(
            Twist,
            '/diff_cont/cmd_vel_unstamped',
            10)

        # Publisher: camera servo commands → esp32_wifi_bridge
        self.servo_cmd_pub = self.create_publisher(
            String,
            '/camera_servo_cmd',
            10)

        # -----------------------------
        # Axis Mapping (Your Controller)
        # -----------------------------
        self.linear_axis = 1          # Left stick Up/Down
        self.angular_axis = 2         # Right stick Left/Right

        self.dpad_horizontal = 6      # Left/Right
        self.dpad_vertical = 7        # Up/Down

        # -----------------------------
        # Right-Side Face Button Mapping
        # PS2/Xbox style: A=0, B=1, X=3, Y=4
        # (Adjust indices here if your controller differs)
        # -----------------------------
        self.btn_A = 0   # Pitch DOWN  (+5 degrees, camera tilts down)
        self.btn_B = 1   # Yaw RIGHT   (+5 degrees)
        self.btn_X = 3   # Yaw LEFT    (-5 degrees)
        self.btn_Y = 4   # Pitch UP    (-5 degrees, camera tilts up)

        # -----------------------------
        # Select / Start Button Mapping
        # PS2 style: Select=8, Start=9
        # (Adjust indices here if your controller differs)
        # -----------------------------
        self.btn_SELECT = 10   # Go to PARKED position  (yaw=100°, pitch=90°)
        self.btn_START  = 11   # Go to DEFAULT SCAN pos (yaw=10°,  pitch=90°)

        # -----------------------------
        # Status Shortcut Button Mapping
        # Buttons 6-9 publish preset /bot_status messages
        # -----------------------------
        self.btn_STATUS_6 = 6   # Reached Aisle_2/Row_1/Rack_1
        self.btn_STATUS_7 = 7   # Reached Aisle_1/Row_1/Rack_1
        self.btn_STATUS_8 = 8   # Reached Aisle_2/Row_1/Rack_2
        self.btn_STATUS_9 = 9   # Reached Aisle_1/Row_1/Rack_2

        self.STATUS_MESSAGES = {
            6: "Reached Aisle_2/Row_1/Rack_1",
            7: "Reached Aisle_1/Row_1/Rack_1",
            8: "Reached Aisle_2/Row_1/Rack_2",
            9: "Reached Aisle_1/Row_1/Rack_2",
        }

        # Preset positions — must match rack_scanner_node constants
        self.PARKED_YAW    = 100
        self.PARKED_PITCH  = 90
        self.DEFAULT_YAW   = 10
        self.DEFAULT_PITCH = 90

        # -----------------------------
        # Servo State
        # -----------------------------
        self.servo_yaw   = 100      # Start at parked yaw position
        self.servo_pitch = 90       # Start at parked pitch position

        self.PITCH_MIN = 20         # Servo hardware limit (tilt up)
        self.PITCH_MAX = 160        # Servo hardware limit (tilt down)
        self.YAW_MIN   = 0
        self.YAW_MAX   = 180
        self.SERVO_STEP = 5         # Degrees per button press
        self.SERVO_SPEED = 20       # Speed value forwarded to ESP32

        # Debounce: track previous button states to detect press edges
        self.prev_btn_A      = 0
        self.prev_btn_B      = 0
        self.prev_btn_X      = 0
        self.prev_btn_Y      = 0
        self.prev_btn_SELECT = 0
        self.prev_btn_START  = 0
        self.prev_btn_6      = 0
        self.prev_btn_7      = 0
        self.prev_btn_8      = 0
        self.prev_btn_9      = 0

        # -----------------------------
        # Speed Limits
        # -----------------------------
        self.linear_scale = 0.5       # m/s
        self.angular_scale = 1.5      # rad/s

        self.min_linear = 0.1
        self.max_linear = 5.0

        self.min_angular = 0.2
        self.max_angular = 5.0

        # Debounce variables
        self.prev_dpad_vertical = 0
        self.prev_dpad_horizontal = 0

        self.get_logger().info("PS2 Teleop Started")
        self.get_logger().info(
            f"Camera servo parked at yaw={self.servo_yaw}°, pitch={self.servo_pitch}° "
            f"| Step={self.SERVO_STEP}° | Pitch limits=[{self.PITCH_MIN}°, {self.PITCH_MAX}°]"
        )

        self.print_speed()

    def print_speed(self):
        self.get_logger().info(
            "\n"
            "=============================\n"
            f" Linear Speed  : {self.linear_scale:.2f} m/s\n"
            f" Angular Speed : {self.angular_scale:.2f} rad/s\n"
            "============================="
        )

    def joy_callback(self, msg):

        # -----------------------------
        # D-Pad Up / Down
        # -----------------------------
        dpad_v = int(msg.axes[self.dpad_vertical])

        if dpad_v != self.prev_dpad_vertical:

            if dpad_v == 1:

                self.linear_scale *= 1.10
                self.linear_scale = min(self.linear_scale,
                                        self.max_linear)

                self.print_speed()

            elif dpad_v == -1:

                self.linear_scale *= 0.90
                self.linear_scale = max(self.linear_scale,
                                        self.min_linear)

                self.print_speed()

        self.prev_dpad_vertical = dpad_v

        # -----------------------------
        # D-Pad Left / Right
        # -----------------------------
        dpad_h = int(msg.axes[self.dpad_horizontal])

        if dpad_h != self.prev_dpad_horizontal:

            if dpad_h == -1:

                self.angular_scale *= 1.10
                self.angular_scale = min(self.angular_scale,
                                         self.max_angular)

                self.print_speed()

            elif dpad_h == 1:

                self.angular_scale *= 0.90
                self.angular_scale = max(self.angular_scale,
                                         self.min_angular)

                self.print_speed()

        self.prev_dpad_horizontal = dpad_h

        # -----------------------------
        # Face Button Servo Control
        # Y = Pitch Up | A = Pitch Down
        # B = Yaw Right | X = Yaw Left
        # (Each press = SERVO_STEP degrees)
        # -----------------------------
        num_buttons = len(msg.buttons)

        def btn(idx):
            return int(msg.buttons[idx]) if idx < num_buttons else 0

        cur_A = btn(self.btn_A)
        cur_B = btn(self.btn_B)
        cur_X = btn(self.btn_X)
        cur_Y = btn(self.btn_Y)

        servo_changed = False
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

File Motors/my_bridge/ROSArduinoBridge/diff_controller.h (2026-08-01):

/* Functions and type-defs for PID control.

   Taken mostly from Mike Ferguson's ArbotiX code which lives at:
   
   http://vanadium-ros-pkg.googlecode.com/svn/trunk/arbotix/
*/

/* PID setpoint info For a Motor */
typedef struct {
  double TargetTicksPerFrame;    // target speed in ticks per frame
  long Encoder;                  // encoder count
  long PrevEnc;                  // last encoder count

  /*
  * Using previous input (PrevInput) instead of PrevError to avoid derivative kick,
  * see http://brettbeauregard.com/blog/2011/04/improving-the-beginner%E2%80%99s-pid-derivative-kick/
  */
  int PrevInput;                // last input
  //int PrevErr;                   // last error

  /*
  * Using integrated term (ITerm) instead of integrated error (Ierror),
  * to allow tuning changes,
  * see http://brettbeauregard.com/blog/2011/04/improving-the-beginner%E2%80%99s-pid-tuning-changes/
  */
  //int Ierror;
  int ITerm;                    //integrated term

  long output;                    // last motor setting
}
SetPointInfo;

SetPointInfo leftPID, rightPID;

/* PID Parameters */
int Kp = 20;
int Kd = 12;
int Ki = 2;
int Ko = 50;

unsigned char moving = 0; // is the base in motion?

/*
* Initialize PID variables to zero to prevent startup spikes
* when turning PID on to start moving
* In particular, assign both Encoder and PrevEnc the current encoder value
* See http://brettbeauregard.com/blog/2011/04/improving-the-beginner%E2%80%99s-pid-initialization/
* Note that the assumption here is that PID is only turned on
* when going from stop to moving, that's why we can init everything on zero.
*/
void resetPID(){
   leftPID.TargetTicksPerFrame = 0.0;
   leftPID.Encoder = readEncoder(LEFT);
   leftPID.PrevEnc = leftPID.Encoder;
   leftPID.output = 0;
   leftPID.PrevInput = 0;
   leftPID.ITerm = 0;

   rightPID.TargetTicksPerFrame = 0.0;
   rightPID.Encoder = readEncoder(RIGHT);
   rightPID.PrevEnc = rightPID.Encoder;
   rightPID.output = 0;
   rightPID.PrevInput = 0;
   rightPID.ITerm = 0;
}

/* PID routine to compute the next motor commands */
void doPID(SetPointInfo * p) {
  long Perror;
  long output;
  int input;

  //Perror = p->TargetTicksPerFrame - (p->Encoder - p->PrevEnc);
  input = p->Encoder - p->PrevEnc;
  Perror = p->TargetTicksPerFrame - input;


  /*
  * Avoid derivative kick and allow tuning changes,
  * see http://brettbeauregard.com/blog/2011/04/improving-the-beginner%E2%80%99s-pid-derivative-kick/
  * see http://brettbeauregard.com/blog/2011/04/improving-the-beginner%E2%80%99s-pid-tuning-changes/
  */
  //output = (Kp * Perror + Kd * (Perror - p->PrevErr) + Ki * p->Ierror) / Ko;
  // p->PrevErr = Perror;
  output = (Kp * Perror - Kd * (input - p->PrevInput) + p->ITerm) / Ko;
  p->PrevEnc = p->Encoder;

  output += p->output;
  // Accumulate Integral error *or* Limit output.
  // Stop accumulating when output saturates
  if (output >= MAX_PWM)
    output = MAX_PWM;
  else if (output <= -MAX_PWM)
    output = -MAX_PWM;
  else
  /*
  * allow turning changes, see http://brettbeauregard.com/blog/2011/04/improving-the-beginner%E2%80%99s-pid-tuning-changes/
  */
    p->ITerm += Ki * Perror;

  p->output = output;
  p->PrevInput = input;
}

/* Read the encoder values and call the PID routine */
void updatePID() {
  /* Read the encoders */
  leftPID.Encoder = readEncoder(LEFT);
  rightPID.Encoder = readEncoder(RIGHT);
  
  /* If we're not moving there is nothing more to do */
  if (!moving){
    /*
    * Reset PIDs once, to prevent startup spikes,
    * see http://brettbeauregard.com/blog/2011/04/improving-the-beginner%E2%80%99s-pid-initialization/
    * PrevInput is considered a good proxy to detect
    * whether reset has already happened
    */
    if (leftPID.PrevInput != 0 || rightPID.PrevInput != 0) resetPID();
    return;
  }

  /* Compute PID update for each motor */
  doPID(&rightPID);
  doPID(&leftPID);

  /* Set the motor speeds accordingly */
  setMotorSpeeds(leftPID.output, rightPID.output);
}

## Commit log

2026-08-01 Initial commit: Warehouse Bot ROS2 packages, active vision scanner, hardware interfaces, and package documentation
    [base_mobile.xacro, common_properties.xacro, my_controllers.yaml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]
2026-08-06 feat(navigation): add delayed execution of initial pose script in navigation launch & update documentation
    [warehouse_database.xlsx]
2026-08-06 refactor(repo): structure scripts into scripts/ directory, add chassis STEP model, presentation slides, and update navigation launch paths
    [WareOps_BOT.step]
